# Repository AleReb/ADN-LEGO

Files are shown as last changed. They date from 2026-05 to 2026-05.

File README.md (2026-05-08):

# ADN LEGO

Simulador didactico de lector/secuenciador de ADN hecho con una placa ESP32-S3 SuperMini, un sensor de color TCS34725, una pantalla OLED I2C, botones de control y un motor paso a paso. La muestra fisica se representa con piezas o marcas de color que pasan frente al sensor; cada color se traduce a una base de ADN.

## Idea del proyecto

El equipo no secuencia ADN real. Simula el principio de lectura por posiciones: el motor mueve una tira o mecanismo LEGO una distancia fija, el sensor detecta el color en la nueva posicion y el firmware lo convierte en una base:

| Color | Base |
| --- | --- |
| Azul | A |
| Rojo | T |
| Verde | G |
| Amarillo | C |
| Sin lectura clara | N |

La secuencia se acumula en memoria, se muestra en la OLED y se imprime por el monitor Serial.

## Estructura del repositorio

```text
.
|-- lego_adnV2/
|   `-- lego_adnV2.ino      # Firmware Arduino/ESP32
`-- pcb/
    |-- adn_Lego.sch        # Esquematico EAGLE
    |-- adn_Lego.brd        # PCB EAGLE
    |-- adn_Lego_*.job      # Jobs/CAM de EAGLE
    `-- eagle.epf           # Proyecto EAGLE
```

## Hardware documentado en el PCB

El esquematico `pcb/adn_Lego.sch` contiene estos bloques:

| Nombre en PCB | Funcion |
| --- | --- |
| `ESP32S3_SUPERMINI` | Controlador principal |
| `U$1` | Pantalla OLED 128x64 I2C |
| `RGB` | Conector I2C para sensor de color TCS34725 |
| `I2C2` | Segundo conector I2C auxiliar |
| `SV1` | Conector de motor |
| `SW1` | Boton reset/nueva secuencia |
| `SW2` | Boton retroceder |
| `SW3` | Boton avanzar/leer base |
| `EXP/S3` | Header de expansion |

## Mapa de pines usado por el firmware

| Senal | GPIO ESP32-S3 |
| --- | --- |
| Motor IN1 | GPIO4 |
| Motor IN2 | GPIO3 |
| Motor IN3 | GPIO2 |
| Motor IN4 | GPIO1 |
| Boton reset | GPIO5 |
| Boton retroceder | GPIO6 |
| Boton avanzar | GPIO7 |
| I2C SDA | GPIO8 |
| I2C SCL | GPIO9 |

El firmware fuerza `Wire.begin(8, 9)` para coincidir con el PCB.

## Dependencias de Arduino

Instalar desde el Library Manager:

- `Adafruit TCS34725`
- `Adafruit BusIO`
- `U8g2`

Seleccionar una placa compatible con ESP32-S3 SuperMini en el core de ESP32 para Arduino.

## Uso

1. Abrir `lego_adnV2/lego_adnV2.ino` en Arduino IDE.
2. Seleccionar la placa ESP32-S3 y el puerto correcto.
3. Cargar el sketch.
4. Abrir el monitor Serial a `115200` baudios.
5. Colocar la tira LEGO o plantilla de colores frente al lector.
6. Pulsar avanzar para mover una posicion y leer una base.
7. Pulsar retroceder para volver una posicion y borrar la ultima base.
8. Pulsar reset para iniciar una nueva secuencia.

La salida Serial tiene este formato:

```text
>nueva_secuencia
Base 1: A | Secuencia: A
Base 2: T | Secuencia: AT
Base 3: G | Secuencia: ATG
```

## Cambios realizados al firmware

- Se reemplazo la lectura suelta de colores por un flujo de secuenciacion.
- Se agrego acumulacion de secuencia hasta 64 bases.
- Se agrego salida Serial con indice de base y secuencia completa.
- Se corrigio el I2C para usar SDA `GPIO8` y SCL `GPIO9`, como indica el PCB.
- Se eliminaron dependencias no usadas (`Stepper`, `AsyncStepperLib`, `cstring`).
- Se agrego liberacion de bobinas del motor despues de cada movimiento.
- Se normalizo la clasificacion de color usando proporciones RGB, menos sensible a cambios de brillo que valores absolutos.
- Se agrego lectura `N` cuando el color no es confiable.

## Ajustes necesarios para que funcione bien como simulador

Estos parametros estan al inicio de `lego_adnV2.ino` y probablemente deben calibrarse en el prototipo fisico:

| Parametro | Valor actual | Que ajustar |
| --- | --- | --- |
| `stepsPerBase` | `845` | Pasos entre dos colores consecutivos de la tira LEGO |
| `stepDelayMs` | `1` | Velocidad del motor; subir si pierde pasos |
| `readSettleMs` | `250` | Pausa despues de mover antes de leer color |
| `minClearToRead` | `250` | Umbral minimo de luz para aceptar lectura |
| Reglas de `identifyBase()` | Umbrales RGB normalizados | Afinar si un color se confunde con otro |

Para una version mas robusta, el siguiente cambio recomendado es agregar un modo de calibracion: mantener pulsado reset, presentar Azul/Rojo/Verde/Amarillo, guardar sus valores en memoria y clasificar por distancia al color calibrado.

## Notas del PCB

- El PCB usa I2C compartido para la OLED y el sensor TCS34725.
- La OLED esta en `3V3`.
- El conector `RGB` aparece alimentado desde `5V`; verificar el modulo TCS34725 usado. Muchos modulos toleran `3V3-5V`, pero si el sensor no tiene regulador o conversores de nivel, conviene alimentarlo a `3V3`.
- Los botones estan cableados a GND y el firmware usa `INPUT_PULLUP`.
- El motor requiere una etapa driver externa si el conector `SV1` va a bobinas o a un motor tipo 28BYJ-48. No se debe alimentar un motor directamente desde GPIO del ESP32.

## Estado actual

El proyecto queda preparado como simulador funcional de secuenciador: mueve por pasos, lee colores, traduce a bases A/T/G/C/N, muestra la lectura y construye una secuencia. La precision final depende de la calibracion mecanica de `stepsPerBase`, la iluminacion alrededor del sensor y el contraste de los colores usados.

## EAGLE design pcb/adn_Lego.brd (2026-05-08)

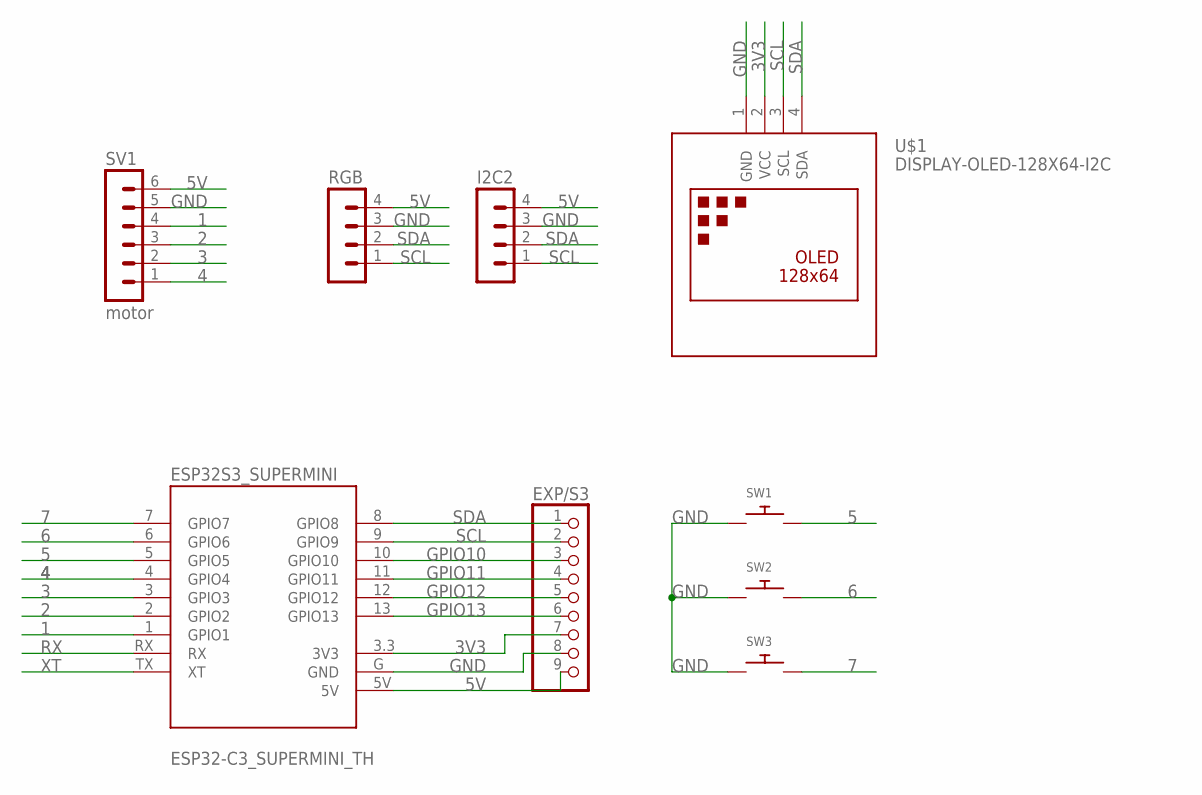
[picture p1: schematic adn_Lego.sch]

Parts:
ESP32S3_SUPERMINI: ESP32-C3_SUPERMINI_TH; MODULE_ESP32-C3_SUPERMINI_TH
EXP/S3: PINHD-1X9; 1X09
I2C2: MA04-1
RGB: MA04-1
SV1: motor; MA06-1
SW1, SW2, SW3: SWITCH_PUSHBUTTONEVQ-PE; TACT_PANA-EVQ
U$1: DISPLAY-OLED-128X64-I2C

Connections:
1: ESP32S3_SUPERMINI.1 (GPIO1), SV1.4
2: ESP32S3_SUPERMINI.2 (GPIO2), SV1.3
3: ESP32S3_SUPERMINI.3 (GPIO3), SV1.2
3V3: ESP32S3_SUPERMINI.3.3 (3V3), EXP/S3.7, U$1.2 (VCC)
4: ESP32S3_SUPERMINI.4 (GPIO4), SV1.1
5: ESP32S3_SUPERMINI.5 (GPIO5), SW1.P$2
5V: ESP32S3_SUPERMINI.5V, EXP/S3.9, I2C2.4, RGB.4, SV1.6
6: ESP32S3_SUPERMINI.6 (GPIO6), SW2.P$2
7: ESP32S3_SUPERMINI.7 (GPIO7), SW3.P$2
GND: ESP32S3_SUPERMINI.G (GND), EXP/S3.8, I2C2.3, RGB.3, SV1.5, SW1.P$1, SW2.P$1, SW3.P$1, U$1.1 (GND)
GPIO10: ESP32S3_SUPERMINI.10 (GPIO10), EXP/S3.3
GPIO11: ESP32S3_SUPERMINI.11 (GPIO11), EXP/S3.4
GPIO12: ESP32S3_SUPERMINI.12 (GPIO12), EXP/S3.5
GPIO13: ESP32S3_SUPERMINI.13 (GPIO13), EXP/S3.6
RX: ESP32S3_SUPERMINI.RX
SCL: ESP32S3_SUPERMINI.9 (GPIO9), EXP/S3.2, I2C2.1, RGB.1, U$1.3 (SCL)
SDA: ESP32S3_SUPERMINI.8 (GPIO8), EXP/S3.1, I2C2.2, RGB.2, U$1.4 (SDA)
XT: ESP32S3_SUPERMINI.TX (XT)

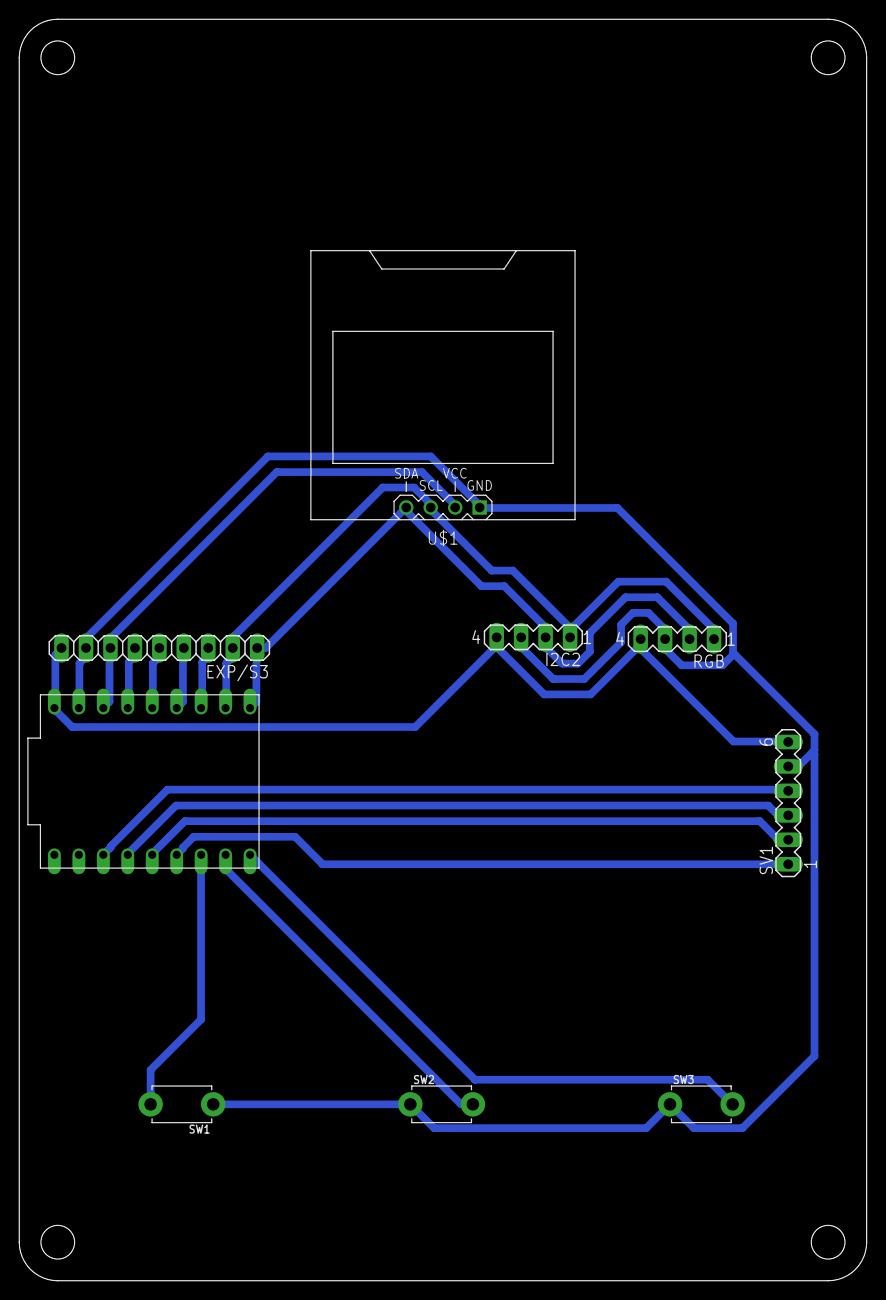
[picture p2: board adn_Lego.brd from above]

Board: 2 copper layers, 88.0 x 131.0 mm, 9 parts (0 on the bottom side), 16 nets.

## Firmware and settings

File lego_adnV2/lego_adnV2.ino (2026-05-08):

/*
  Simulador de lector/secuenciador de ADN con LEGO.

  Mapeo de colores:
  - Azul     -> A
  - Rojo     -> T
  - Verde    -> G
  - Amarillo -> C

  Flujo:
  - Avanzar: mueve una posicion, lee el color y agrega una base.
  - Retroceder: vuelve una posicion y elimina la ultima base leida.
  - Reset: inicia una nueva secuencia.
*/

#include <Wire.h>
#include <Adafruit_TCS34725.h>
#include <U8g2lib.h>

U8G2_SSD1306_128X64_NONAME_F_HW_I2C u8g2(U8G2_R2, U8X8_PIN_NONE);

const uint8_t I2C_SDA = 8;
const uint8_t I2C_SCL = 9;

const uint8_t motorPin1 = 4;
const uint8_t motorPin2 = 3;
const uint8_t motorPin3 = 2;
const uint8_t motorPin4 = 1;

const uint8_t btnReset = 5;
const uint8_t btnBackward = 6;
const uint8_t btnForward = 7;

const int numSteps = 8;
const int stepsLookup[numSteps] = {
  B1000, B1100, B0100, B0110, B0010, B0011, B0001, B1001
};

const int stepsPerBase = 845;
const int stepDelayMs = 1;
const int readSettleMs = 250;
const uint16_t minClearToRead = 250;
const uint8_t maxSequenceLength = 64;

int stepCounter = 0;
uint16_t r, g, b, c;
char sequence[maxSequenceLength + 1] = "";
uint8_t sequenceLength = 0;

bool forwardWasPressed = false;
bool backwardWasPressed = false;
bool resetWasPressed = false;

Adafruit_TCS34725 tcs = Adafruit_TCS34725(
  TCS34725_INTEGRATIONTIME_154MS,
  TCS34725_GAIN_4X
);

void setOutput(int step) {
  digitalWrite(motorPin1, bitRead(stepsLookup[step], 0));
  digitalWrite(motorPin2, bitRead(stepsLookup[step], 1));
  digitalWrite(motorPin3, bitRead(stepsLookup[step], 2));
  digitalWrite(motorPin4, bitRead(stepsLookup[step], 3));
}

void releaseMotor() {
  digitalWrite(motorPin1, LOW);
  digitalWrite(motorPin2, LOW);
  digitalWrite(motorPin3, LOW);
  digitalWrite(motorPin4, LOW);
}

void clockwiseStep() {
  stepCounter++;
  if (stepCounter >= numSteps) {
    stepCounter = 0;
  }
  setOutput(stepCounter);
}

void anticlockwiseStep() {
  stepCounter--;
  if (stepCounter < 0) {
    stepCounter = numSteps - 1;
  }
  setOutput(stepCounter);
}

void moveSteps(int steps, bool forward) {
  for (int i = 0; i < steps; i++) {
    if (forward) {
      anticlockwiseStep();
    } else {
      clockwiseStep();
    }
    delay(stepDelayMs);
  }
  releaseMotor();
}

void readColor() {
  tcs.getRawData(&r, &g, &b, &c);
}

char identifyBase(uint16_t red, uint16_t green, uint16_t blue, uint16_t clear) {
  if (clear < minClearToRead) {
    return 'N';
  }

  uint32_t total = (uint32_t)red + green + blue;
  if (total == 0) {
    return 'N';
  }

  uint16_t rn = (uint32_t)red * 1000 / total;
  uint16_t gn = (uint32_t)green * 1000 / total;
  uint16_t bn = (uint32_t)blue * 1000 / total;

  if (bn > 430 && bn > rn + 90 && bn > gn + 60) {
    return 'A';
  }
  if (rn > 430 && rn > gn + 80 && rn > bn + 100) {
    return 'T';
  }
  if (gn > 420 && gn > rn + 70 && gn > bn + 70) {
    return 'G';
  }
  if (rn > 360 && gn > 330 && bn < 300) {
    return 'C';
  }

  return 'N';
}

const char *baseName(char base) {
  switch (base) {
    case 'A': return "A Azul";
    case 'T': return "T Rojo";
    case 'G': return "G Verde";
    case 'C': return "C Amarillo";
    default: return "N No leido";
  }
}

void appendBase(char base) {
  if (sequenceLength >= maxSequenceLength) {
    return;
  }
  sequence[sequenceLength++] = base;
  sequence[sequenceLength] = '\0';
}

void removeLastBase() {
  if (sequenceLength == 0) {
    return;
  }
  sequence[--sequenceLength] = '\0';
}

void resetSequence() {
  sequenceLength = 0;
  sequence[0] = '\0';
  Serial.println();
  Serial.println(">nueva_secuencia");
}

void printSequence(char lastBase) {
  Serial.print("Base ");
  Serial.print(sequenceLength);
  Serial.print(": ");
  Serial.print(lastBase);
  Serial.print(" | Secuencia: ");
  Serial.println(sequence);
}

void drawDisplay(char lastBase) {
  u8g2.clearBuffer();
  u8g2.setFont(u8g2_font_6x10_tf);
  u8g2.drawStr(0, 9, "ADN LEGO Sequencer");

  u8g2.drawStr(0, 21, baseName(lastBase));

  char line[24];
  snprintf(line, sizeof(line), "R:%u G:%u", r, g);
  u8g2.drawStr(0, 33, line);
  snprintf(line, sizeof(line), "B:%u C:%u", b, c);
  u8g2.drawStr(0, 44, line);

  snprintf(line, sizeof(line), "Bases:%u", sequenceLength);
  u8g2.drawStr(0, 55, line);

  const uint8_t visibleChars = 18;
  const char *visibleSequence = sequence;
  if (sequenceLength > visibleChars) {
    visibleSequence = sequence + sequenceLength - visibleChars;
  }
  u8g2.drawStr(55, 55, visibleSequence);
  u8g2.sendBuffer();
}

void setup() {
  Serial.begin(115200);

  pinMode(motorPin1, OUTPUT);
  pinMode(motorPin2, OUTPUT);
  pinMode(motorPin3, OUTPUT);
  pinMode(motorPin4, OUTPUT);
  releaseMotor();

  pinMode(btnReset, INPUT_PULLUP);
  pinMode(btnForward, INPUT_PULLUP);
  pinMode(btnBackward, INPUT_PULLUP);

  Wire.begin(I2C_SDA, I2C_SCL);
  u8g2.begin();

  u8g2.clearBuffer();
  u8g2.setFont(u8g2_font_6x10_tf);
  u8g2.drawStr(0, 12, "Iniciando sensor...");
  u8g2.sendBuffer();

  if (!tcs.begin()) {
    Serial.println("Error: sensor TCS34725 no encontrado");
    u8g2.clearBuffer();
    u8g2.drawStr(0, 12, "TCS34725 no encontrado");
    u8g2.drawStr(0, 26, "Revise SDA/SCL/3V3/GND");
    u8g2.sendBuffer();
  } else {
    Serial.println("TCS34725 OK");
    resetSequence();
  }
}

void loop() {
  readColor();
  char currentBase = identifyBase(r, g, b, c);
  drawDisplay(currentBase);

  bool forwardPressed = digitalRead(btnForward) == LOW;
  bool backwardPressed = digitalRead(btnBackward) == LOW;
  bool resetPressed = digitalRead(btnReset) == LOW;

  if (forwardPressed && !forwardWasPressed) {
    moveSteps(stepsPerBase, true);
    delay(readSettleMs);
    readColor();
    currentBase = identifyBase(r, g, b, c);
    appendBase(currentBase);
    printSequence(currentBase);
    drawDisplay(currentBase);
  }

  if (backwardPressed && !backwardWasPressed) {
    moveSteps(stepsPerBase, false);
    removeLastBase();
    Serial.print("Retroceso | Secuencia: ");
    Serial.println(sequence);
    drawDisplay(currentBase);
  }

  if (resetPressed && !resetWasPressed) {
    resetSequence();
    drawDisplay(currentBase);
  }

  forwardWasPressed = forwardPressed;
  backwardWasPressed = backwardPressed;
  resetWasPressed = resetPressed;

  delay(25);
}

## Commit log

2026-05-07 Refactor code structure for improved readability and maintainability
    [adn_Lego.brd, adn_Lego.sch]
2026-05-07 Add initial implementation of motor control and color detection features
2026-05-08 Add Fusion synchronization support and update README for ADN LEGO project
    - Updated ADN LEGO PCB file to include Fusion sync attributes.
    - Added warning notes regarding Fusion synchronization and URN support in EAGLE.
    - Removed unused library reference from eagle.epf.
    - Adjusted screen resolution in eagle.epf for better display.
    - Created README.md to document project details, hardware structure, pin mapping, dependencies, usage instructions, firmware changes, and PCB notes.
    [adn_Lego.brd]

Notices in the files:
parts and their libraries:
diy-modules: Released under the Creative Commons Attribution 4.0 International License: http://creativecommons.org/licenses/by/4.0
